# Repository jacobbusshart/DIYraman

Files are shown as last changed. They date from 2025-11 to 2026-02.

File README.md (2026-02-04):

# DIYraman – Open Hardware Raman Spectrometer

  

**Build, understand, and modify your own Raman spectrometer.**
*A modular platform aimed at hobbyists, educators, and low-resource labs.* 

[docs.diyraman.com](https://docs.diyraman.com)
## Introduction

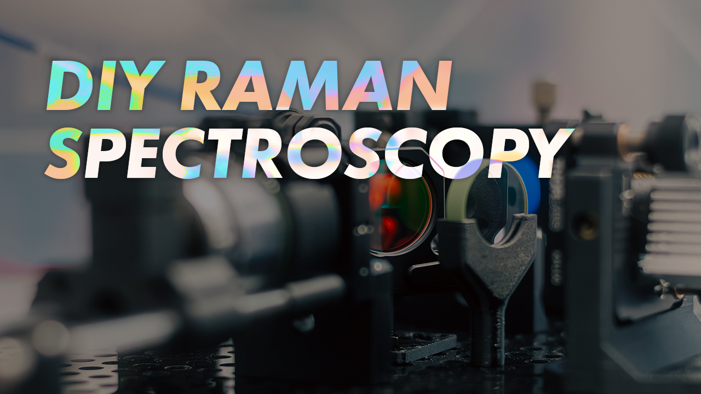
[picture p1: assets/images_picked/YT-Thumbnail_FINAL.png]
https://www.youtube.com/watch?v=EOOmlQH1UKw


[**Click here to watch the Youtube video!**](https://www.youtube.com/watch?v=EOOmlQH1UKw)

Watch the Youtube video to get started and learn about the principles of Raman Spectroscopy, a build overview, along with part considerations, challenges, limitations and practical decisions.  

---

## Project Scope

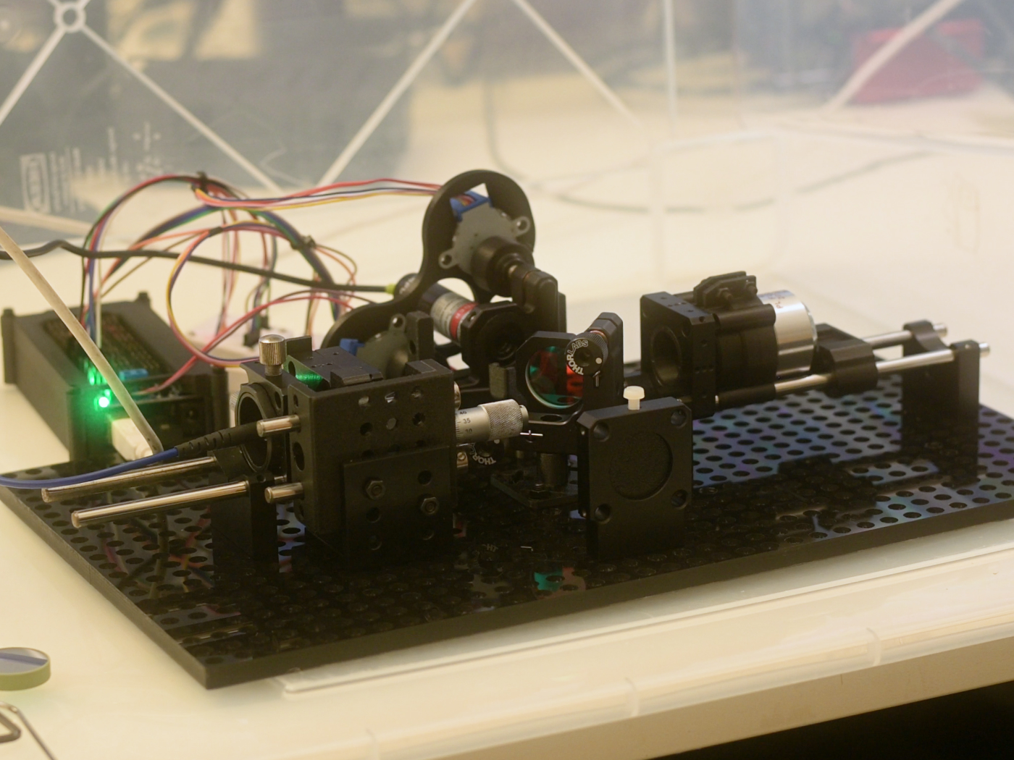
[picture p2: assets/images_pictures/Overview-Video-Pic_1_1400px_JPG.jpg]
Full Assembly in Overpressure Glove Box


**DIYraman** aims to make Raman spectroscopy **replicable, affordable, and fully documented**.

Raman spectroscopy allows for the identification of substances by analyzing how light interacts with molecular vibrations. Historically, this equipment costs tens of thousands of dollars. This project aims to provide instructions for interested tinkerers, who are looking for a documented, applicable build. 

**Key Applications**
* **Identify Substances:** Broad identification of plastics, solvents, and minerals.
* **Qualitative Screening:** Exploratory analysis of pharmaceuticals (e.g., pill composition).
* **Teach Optics:** A hands-on platform for learning spectroscopy and photonics.

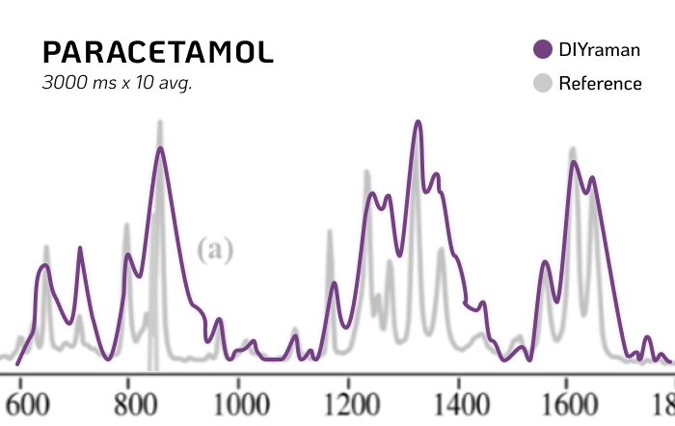
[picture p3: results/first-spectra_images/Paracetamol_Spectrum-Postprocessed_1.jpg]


> 💡 This README is a *project overview*. Detailed build instructions are available on **[docs.diyraman.com](https://docs.diyraman.com)** or can be found in `docs/` on the dedicated pages. An overview of the build instructions can be found further down under [Build Overview](#Build%20Overview).

---

## Component Selection

To balance cost with performance, DIYraman uses a "hybrid" approach: Professional filtering optics combined with repurposed spectroscopy hardware and 3D-printed mechanics.

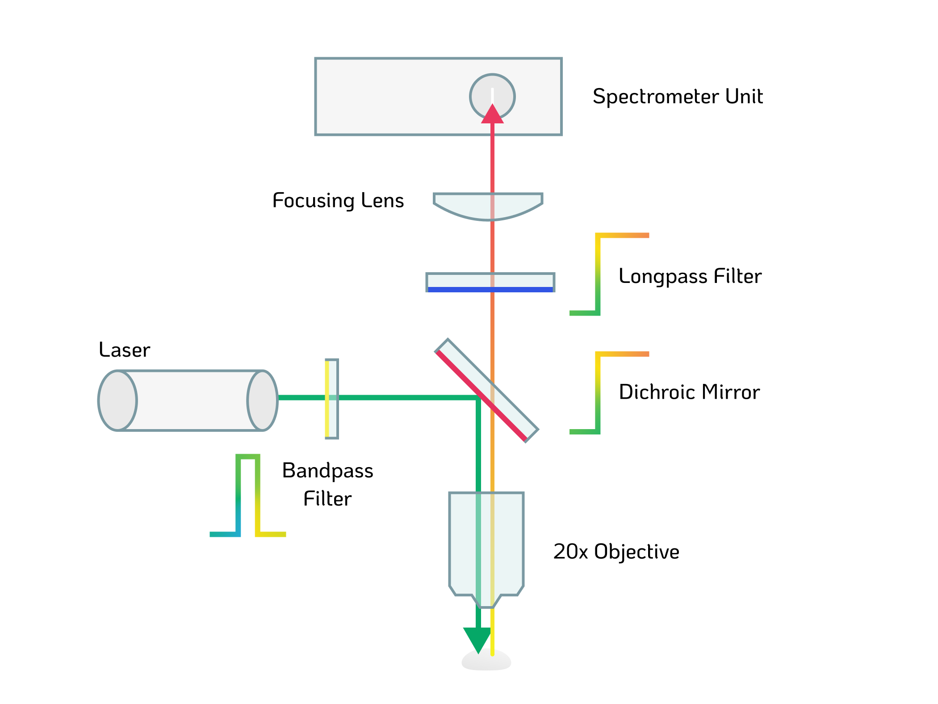
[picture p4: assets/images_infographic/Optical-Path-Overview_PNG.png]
Optical Path Overview


* **Spectrometer:** Surplus BTC100-2S unit (available on [eBay](https://www.ebay.com/itm/143989529085))
* **Excitation:** Cost-effective 532nm DPSS laser pointer
* **Mechanics:** Fully 3D-printable modular stages and enclosures
* **Critical Optics:** High-quality dichroic mirrors and filters (Thorlabs/Edmund Optics) are used to ensure signal integrity.
	* Thorlabs Longpass Dichroic Mirror [DMLP550](https://www.thorlabs.com/item/DMLP550)
	* Thorlabs Longpass Filter [FELH0550](https://www.thorlabs.com/item/FELH0550)

**Bill of Materials**
A detailed cost breakdown and parts list is available in the [BOM (Bill of Materials)](bom/BOM.md) .

---

## Build Overview

The following build path is recommended for a complete and coherent build-experience. The table reflects the current development status of the project's modules. Best viewed and navigated by visiting the [docs.diyraman.com](docs.diyraman.com) page!

*Please note that at this point in time the reproducibility has not been externally validated, as I'm working on the next iteration to optimize and facilitate the entire setup. Until then, view this project as a documentation of my journey into DIY Raman spectroscopy.*

| Step  | Module | Description | Status |
| :---- | :--- | :--- | :--- |
| **0** | **[Introduction](docs/Introduction.md)** | How all the parts work and why they were chosen. | 🟡 Unpolished  |
| **1** | **[Spectrometer-Setup](docs/Spectrometer-Setup.md)** <br>+ [SpectrumStudio-Cheatsheet](docs/SpectrumStudio-Cheatsheet.md)<br>+ [Align-with-Fluorescence](docs/Align-with-Fluorescence.md) | Setup and testing of the B&W Tek spectrometer. | ✅ Ready |
| **2** | **[Dustproof-Workspace](docs/Dustproof-Workspace.md)** | DIY overpressure glovebox construction to keep optics dust-free. | ✅ Ready |
| **3** | **[Core-Assembly](docs/Core-Assembly.md)** | Essential optical assembly to acquire first Raman spectra. | ✅ Ready |
| **4** | **[DIY-Linear-Stage](docs/DIY-Linear-Stage.md)** | DIY build of a low-cost linear translation stage for fine focus adjustments. | 🟡 WiP |
| **5** | Full-Build | Motorization and integration of Linear Stage. | 🔴 Unpublished |
| **6** | Software / GUI | Custom acquisition and visualization software. | 🔴 Unpublished |

> **Status Key:** ✅ = Verified & Documented | 🟡 = Usable, Docs in Progress | 🟠 = Draft / Unstable | 🔴 = Planned / Unpublished

---

## Capabilities

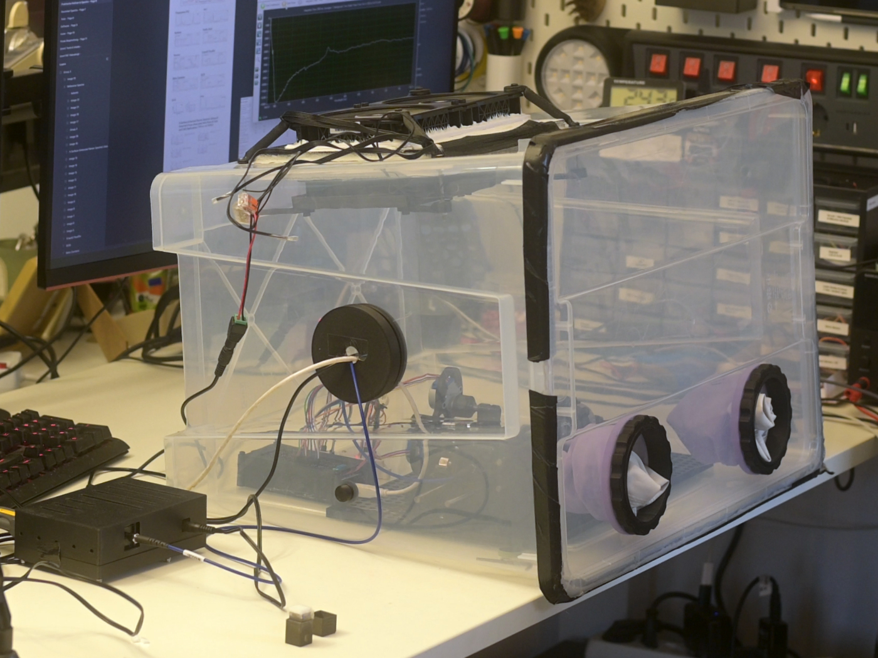
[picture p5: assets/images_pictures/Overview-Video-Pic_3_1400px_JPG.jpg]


| Feature | Specification |
| :--- | :--- |
| **Spectral Range** | Stokes region > ~600 cm⁻¹ |
| **Sample Type** | Solids & Liquids (Cuvette holder) |
| **Resolution** | estimated 35 cm⁻¹ (dependent on spectrometer input slit / sensor & laser beam quality) |
| **Safety** | Wear laser safety protection during alignment or until the optical path is entirely enclosed! |

> 🧪 **Drug / counterfeit screening**  
> The system can be used for *exploratory, educational* screening of unknowns (e.g. counterfeit pills) but **must not** be treated as a validated forensic tool. **Always cross-check with certified methods!**

---

## Repository Structure

- `docs/` — the build instructions hosted on [docs.diyraman.com](docs.diyraman.com)
- `bom/` — BOM tables and sourcing notes  
- `parts/` — files for printing / 3d-models (.stl)  */feel free to contact me for the full Fusion (.F3D) project file*
- `assets/` — all images, diagrams, misc. media  
- `results/` — example spectra / early outputs  
- `software/` — acquisition and post-processing software (unreleased, planned)

---

## Contributing

Contributions are welcome from makers, scientists, and coders. Areas for contribution include:

1. **Testing:** Reporting unclear steps or missing files in the documentation.
2. **Design:** Proposing improved mechanical mounts or variants.
3. **Coding:** Assisting with the upcoming GUI/Firmware.
4. **Sharing:** Submitting example spectra.

**Citation:** If utilizing DIYRaman for research or teaching, please cite the project:

> **DIYRaman - Open Hardware Raman Spectrometer (GitHub)** 
> _Jacob Busshart, DIYraman.com_

---

## Licenses

A modular licensing structure is used to ensure maximum freedom for hardware and software usage.

- **Hardware (CAD, Schematics):** [CERN-OHL-S v2](LICENSES/CERN_OHL_S_V2.txt)
- **Documentation (Guides, Images):** [CC BY-SA 4.0](LICENSES/CC-BY-SA-4.0.txt)
- **Software (Firmware, GUI):** [MIT License](LICENSES/MIT.txt)

---

### Acknowledgements

_Built on the shoulders of the open science community._

- [OpenRaman.org](https://www.open-raman.org/) & [ThePulsar.be](https://www.thepulsar.be/article/diy-raman-spectroscopy/)
- [PhysicsOpenLab.org](https://physicsopenlab.org/2022/04/22/backscattering-raman-system/)
- [LaserPointerForums Community](https://laserpointerforums.com/threads/b-w-tech-spectrometer-473-module-setup-mods-info.101467/)

---

*NOTE: Some parts of the written documentation have been formatted or translated using AI.*

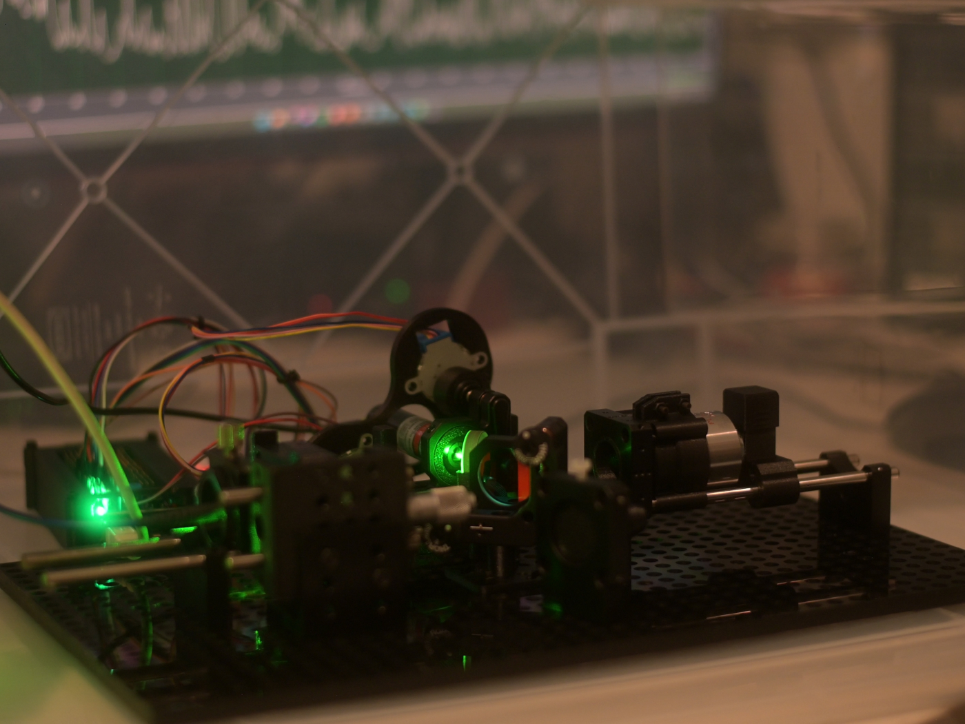
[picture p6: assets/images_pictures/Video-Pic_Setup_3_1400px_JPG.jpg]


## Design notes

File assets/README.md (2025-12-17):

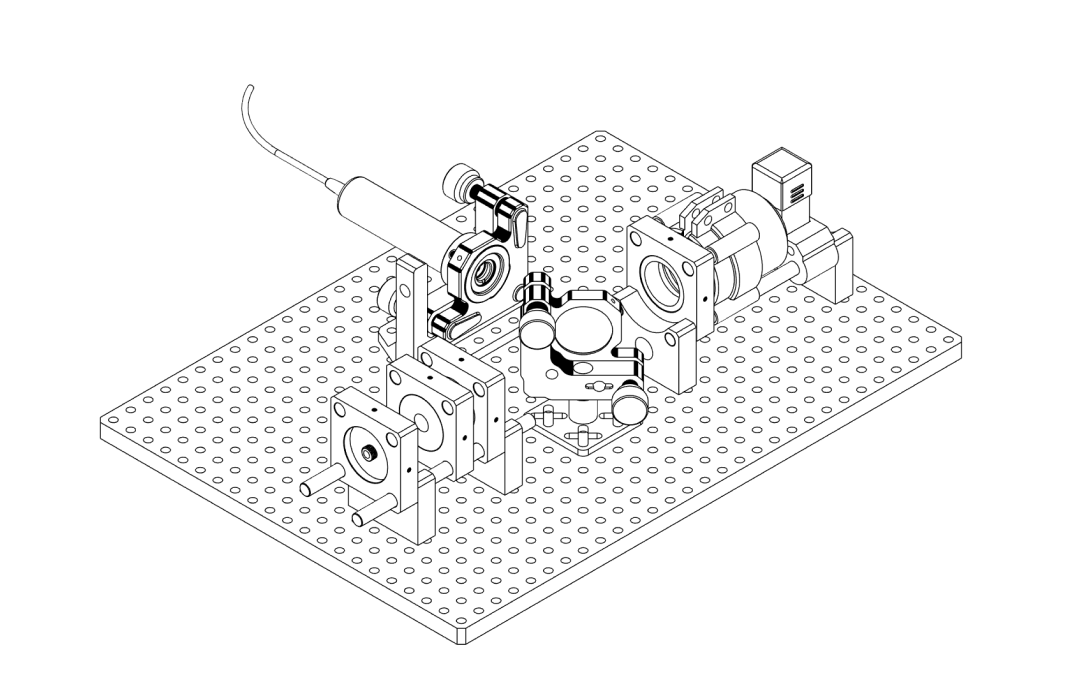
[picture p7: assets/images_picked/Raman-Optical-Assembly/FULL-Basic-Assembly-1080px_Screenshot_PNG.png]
| ***[Core-Assembly](../docs/Core-Assembly.md)*** | <br><center>*abridged version*</center><br> |
| --- | --- |
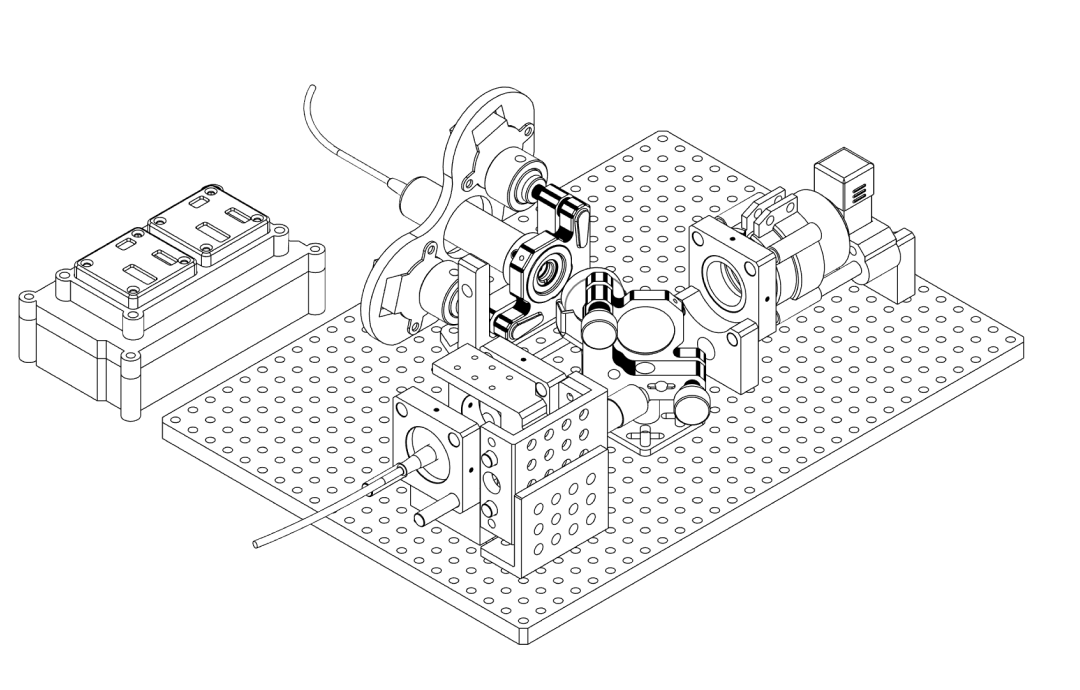
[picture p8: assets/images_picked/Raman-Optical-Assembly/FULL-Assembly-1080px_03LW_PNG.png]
| ***[Full-Build](../docs/Full-Build.md)*** | <br>**<center>*current version*</center>**<br> |

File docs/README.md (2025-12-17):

[Overview - README](../README.md)
[Spectrometer-Setup](Spectrometer-Setup.md)
[Dustproof-Workspace](Dustproof-Workspace.md)
[Core-Assembly](Core-Assembly.md)
[Align-with-Fluorescence](Align-with-Fluorescence.md)
[SpectrumStudio-Cheatsheet](SpectrumStudio-Cheatsheet.md)
[DIY-Linear-Stage](DIY-Linear-Stage.md)
[Full-Build](Full-Build.md)

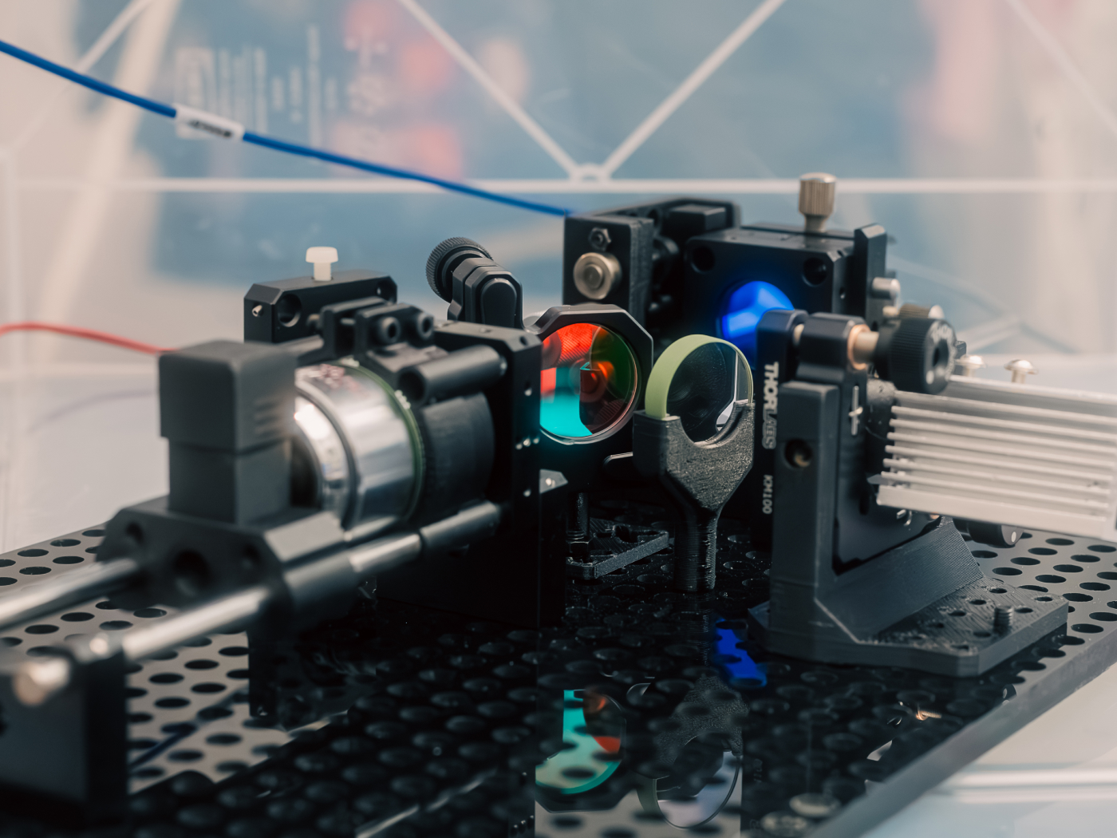
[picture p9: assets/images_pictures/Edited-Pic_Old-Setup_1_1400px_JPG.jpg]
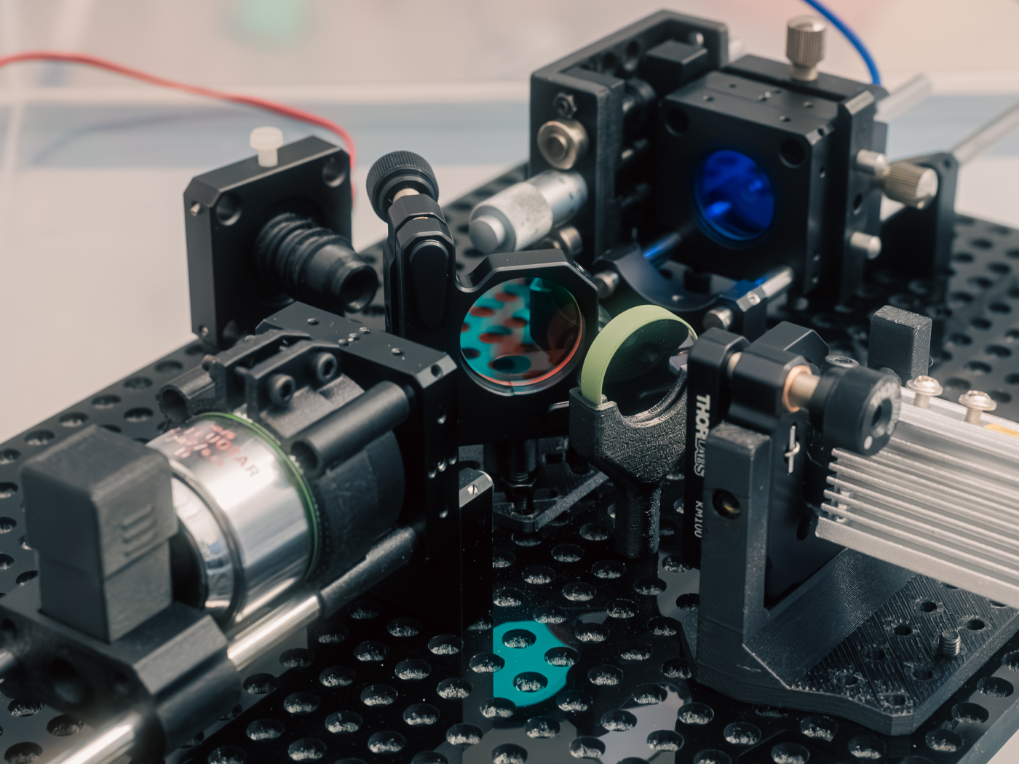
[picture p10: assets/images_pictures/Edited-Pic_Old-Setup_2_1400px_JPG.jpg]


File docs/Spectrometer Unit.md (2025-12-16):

# Measuring light - Spectrometer Unit

Spectrometer unit with printed case

Prepare, house and use the surplus **B&W Tek BTC100-2S** spectrometer module as the detector for the DIYraman system. 

This page focuses on the practical steps you need to:

- **Inspect and clean** the used unit  
- **Mount it** in a simple printed housing  
- **Power it up** and talk to it over RS-232  
- **Acquire a first spectrum** and apply a basic wavelength calibration

| Specs | |
| --- | --- |
| Range | ~400nm - 650nm |
| Grating | 1800l/mm, blaze at 500nm |
| Input slit | 100µm (wide) |
| Coupling | SMA905 fiber |
| Detector | Sony ILX511 linear CCD |
| Resolution | 2048 pixel spectrum |
| Power | 5V barrel jack |
| Connection | RS-232 serial |

View inside the optical assembly of the Spectrometer Unit BTC100-2S

> [!ABSTRACT] Learn more about the BTC100-2S
> For an in-depth look into the capabilities and internal design of this model, visit this blog post: **[“Home Optical Spectrometry: The B&W Tek BTC100-2S”](https://www.sevarg.net/2023/01/28/bw-tek-btc100-spectrometer/)**

---

## Parts and Materials

> [!EXAMPLE] Visit the complete Bill of Materials
> Everything you will need, both printed parts and sourced parts, along with their cost and supplier, can be viewed in the dedicated [BOM](../bom/BOM.md)!

### Sourced parts

| Qty | Name | Model / Spec | Notes |
| --- | --- | --- | --- |
| 1x  | Spectrometer unit | [B&W Tek BTC100-2S](https://www.ebay.com/itm/143989529085) | Or any other spectrometer - ideally with SMA905 input, if you use fiber. |
| 1x  | Fiber optic cable, 200 μm | Any, SMA905-SMA905 1m VIS-IR 200um | - |
| 1x  | Data cable | RS-232 to USB | Choose a chipset compatible with your OS (many FTDI / Prolific chips work reliably). |
| 1x  | Power supply | 5V, ~3A, DC barrel jack | |
| 1x  | Calibration lamp | Dedicated calibration / CFL / mercury-vapor lamp | Needs several sharp lines near ~550 nm for wavelength calibration. |

> [!TIP] Spectrometer cost consideration  
> The used BTC100-2S board - although quite old - will still be significantly cheaper than  buying parts for a DIY spectrometer. If you are lucky (or persistent enough) to spot a great deal of a more modern unit, that's even better.

### Printed parts

| Qty | Part name (.stl) | Print preview |
| --- | --- | --- |
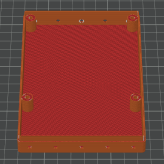
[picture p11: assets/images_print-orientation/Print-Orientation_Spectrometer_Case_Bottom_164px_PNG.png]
| 1x  | `Spectrometer-Case_Bottom` |  |
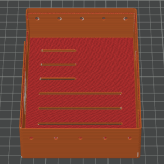
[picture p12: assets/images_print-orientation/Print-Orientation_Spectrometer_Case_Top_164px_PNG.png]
| 1x  | `Spectrometer-Case_Top` |  |
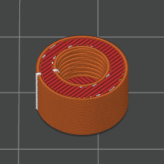
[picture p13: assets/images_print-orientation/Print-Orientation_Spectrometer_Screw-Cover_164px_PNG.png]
| 1x  | `Spectrometer_Screw-Cover` |  |

> [!WARNING] Health & safety – sanding fibre-filled plastics  
> When sanding or trimming 3D-printed parts made from PETG-CF or other fibre-filled filaments, wear at least a surgical mask. Fine carbon or glass fibres can accumulate in your lungs with repeated exposure.

---

## Inspect and Clean the Spectrometer

Before printing parts or powering anything, make sure your spectrometer arrived intact and is free of loose contamination.

### Visual inspection

Spectrometer unit out of the box  
Spectrometer top-rear view with SMA905 input  
Underside of the PCB

Check:

- The **PCB** is not bent, cracked or visibly repaired.  
- The **SMA905 input stud** is straight and firmly attached.  
- The **50 µm slit window** in front of the spectrometer optics is intact (no cracks or chips).  
- The **heatsink, fan and connectors** are firmly attached and not visibly corroded.  

If you spot severe mechanical damage (cracked PCB, broken slit, missing components), contact the seller before investing further time.

### Cleaning

Close-up of the input with 50 µm slit

1. Use a blower or compressed gas to gently **dust off the PCB and the fan**.  
2. Lightly dampen a lint-free cloth with **99% IPA**.  
3. Wipe non-optical surfaces: metal case, heatsink, fan frame, backside of the PCB.  
4. Use cotton swabs with a small amount of IPA to clean tight areas around connectors and edges.  
5. **Do not touch** the slit glass, sensor or any exposed optical surfaces directly.  

> [!WARNING] Avoid optical surfaces
> Don't disassemble the spectrometer's optical assembly or try to adjust any of its components, unless you know what you're doing. Avoid getting any liquid into the input or onto any optical surface. 

---

## Housing and Mounting

The BTC100-2S is an exposed PCB assembly. A simple printed case protects it from dust, stray light and mechanical damage, and makes overall handling easier.

Spectrometer with printed case, standoffs and screws

> [!TIP] Print seams for precise holes  
> Avoid seam placement directly inside precise holes. Random seam positioning often yields better clearance for functional features like standoffs and connector cut-outs.

### Install PCB standoffs

1. Place the `Spectrometer-Case_Bottom` on your work surface.  
2. Identify the four mounting bosses that match the BTC100-2S PCB hole pattern.  
3. Screw the included standoffs into these bosses.
4. Confirm that the height of the standoffs provide enough clearance.

### Mount the spectrometer in the case

1. Carefully lower the BTC100-2S onto the standoffs so that:  
   - All four mounting holes align with the standoffs.  
   - The SMA905 input lines up with the circular opening in the case front.  
2. Fasten the PCB using four M3 screws, tightening them evenly.  
3. Place the `Spectrometer-Case_Top` on the bottom part and close the housing.  

---

## Powering On and Connecting

This section gets the spectrometer powered and talking to your computer.

### Warm-up behaviour

1. Connect the 5V / ≥3A power supply to the barrel jack.  
2. Plug it in – there is no power switch, so you immediately hear the small fan spin up.  
3. Leave the unit on for **≈ 10 minutes** before serious measurements.

> [!INFO] Warm-up time? Cool-down time!  
> The BTC100-2S uses a thermoelectric cooler (TEC) plus heatsink and fan to cool and stabilise the sensor temperature. Starting measurements immediately after power-on leads to higher background noise and random spikes until the temperature settles!

### RS-232 to USB adapter

- Connect the RS-232 adapter between the DB-9 port and your PC.
	- Windows is assumed as the operating system, although it is possible - and tested -to run the original software inside of a virtual machine on an M1 Mac.

> [!NOTE] USB–RS-232 compatibility  
> Some USB-RS-232 chipsets behave poorly on non-Windows systems or inside virtual machines. A mid-range cable from a known brand (e.g. FTDI-based) tends to work more reliably than ultra-cheap clones, according to a forum post.

---

## Acquiring your First Spectrum

For initial testing, use the original B&W Tek software (“Spectrum Studio”) to confirm that communication and data acquisition work as expected.

> [!TIP] Quick UI reference - Cheatsheet 
> See the dedicated page [**Spectrum Studio Cheatsheet**](Spectrum%20Studio%20Cheatsheet.md) for screenshots and an overview of the most relevant controls.

### Software setup

1. Start Spectrum Studio with the spectrometer powered and connected.  
   - In case the program isn't working or executing correctly, run it in **compatibility mode**.
	   - Right-Click > "*Properties*" > "*Compatibility*" > "*Run in comp...*" > Check Box and Select "*Windows 7*" > Press "*OK*".
2. If it does not auto-detect the device:  

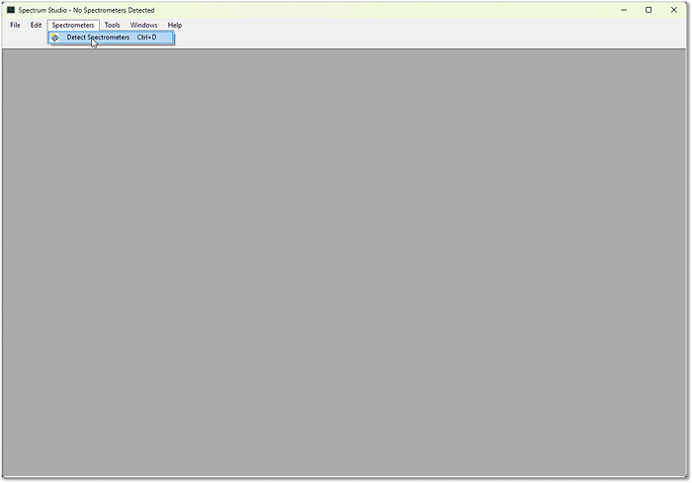
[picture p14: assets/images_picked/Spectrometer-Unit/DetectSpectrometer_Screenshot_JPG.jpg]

   - Click **“Detect Spectrometer”** in the toolbar.  
   
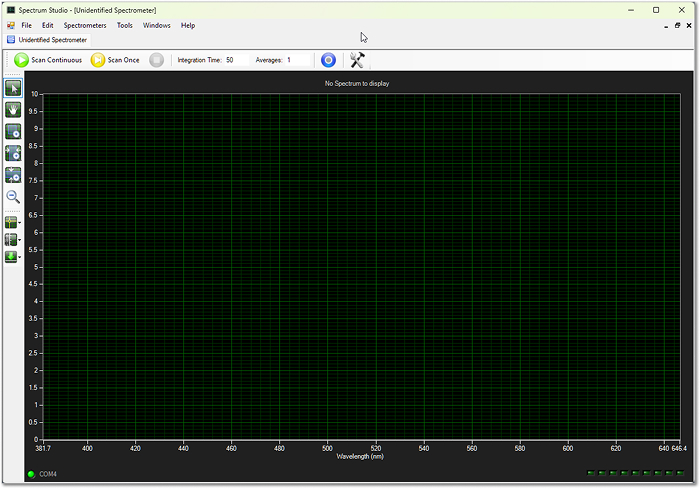
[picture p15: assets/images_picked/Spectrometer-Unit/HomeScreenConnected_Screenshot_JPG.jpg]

   - Wait for the blank graph to appear.  
3. Open the **“Calibrate”** window ( - settings icon at the right of the toolbar).  
4. Set parameter **C1 = 1** at the bottom and confirm with **OK** – this enables the wavelength calibration features you will need later.

### Integration time and averaging

The spectrometer behaves much like a camera sensor:

- **Integration time** ≈ camera shutter speed.  
  - ~50 ms: quick checks and rough alignment.  
  - 1500–20000 ms: typical range for final Raman measurements.  
- **Averages**: number of individual spectra that will be acquired and averaged, even when you press **“Scan Once”**.  
  - During acquisition, the software shows the most recent scan.  
  - At the end of the series, it updates the display with the averaged (and optionally background-subtracted) spectrum.

> [!TIP] Avoid saturation  
> Aim for a maximum signal well below the top of the y-axis. Saturated pixels distort line shapes and make later processing more difficult.

### Capturing and subtracting background

1. Block the input slit (e.g. with your finger, a printed cap or tape).  

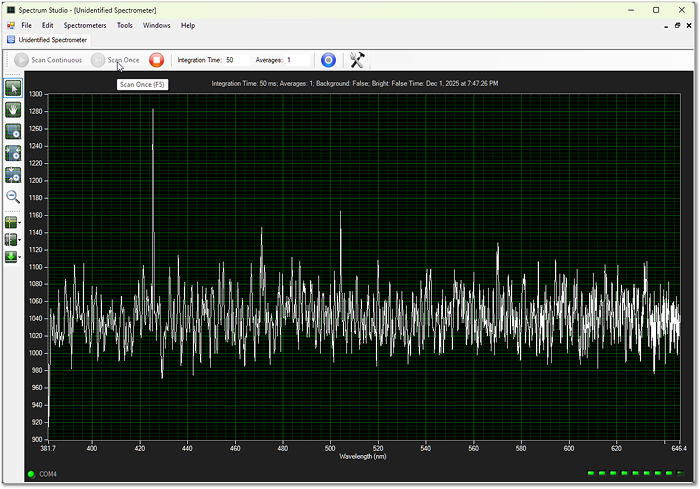
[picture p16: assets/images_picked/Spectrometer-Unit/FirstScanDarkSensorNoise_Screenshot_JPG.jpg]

2. Start an acquisition  with typical settings (e.g. 250–2000 ms, a few averages).  
3. Use the **green arrow icon** in the left toolbar ( - background submenu) to:
   - Capture the current spectrum - the noise print of the dark sensor - as background.

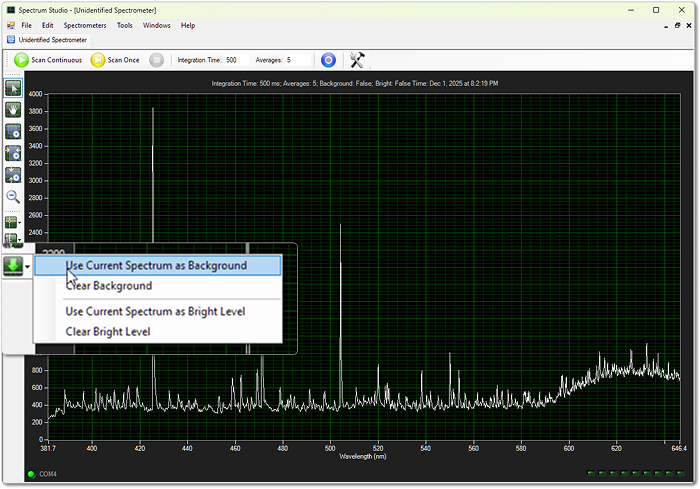
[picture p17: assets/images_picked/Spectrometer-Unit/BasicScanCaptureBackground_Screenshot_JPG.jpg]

4. Scan again to capture a test - using a dedicated light source or just your room

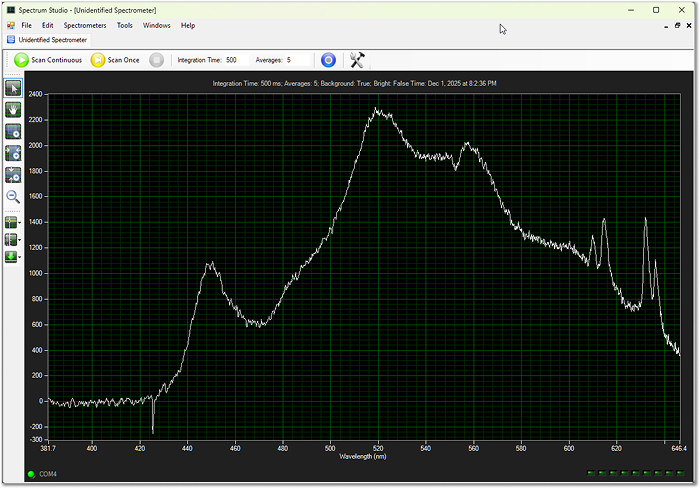
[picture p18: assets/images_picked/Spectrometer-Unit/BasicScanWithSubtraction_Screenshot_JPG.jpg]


This background remains active and will be applied on all subsequent spectra until you clear or update it. The table below highlights the difference in quality of the final spectrum - with and without the subtracted sensor noise.

| With background subtraction (clean) | Without background subtraction (raw) |
| --- | --- |
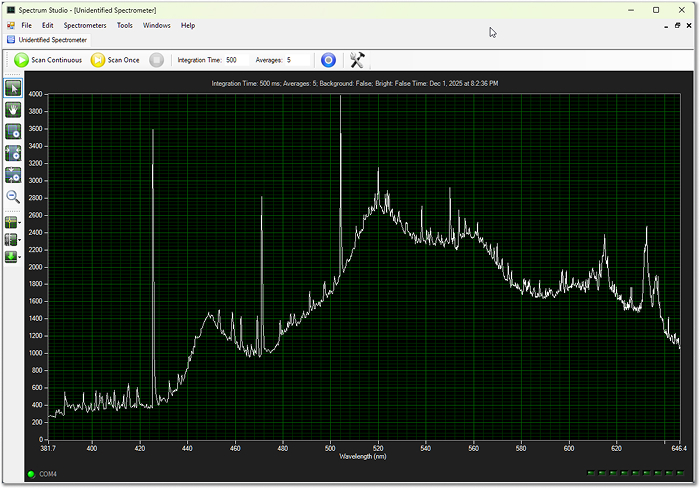
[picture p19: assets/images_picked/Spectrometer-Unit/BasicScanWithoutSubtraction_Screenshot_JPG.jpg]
|  |  |

> [!WARNING] Re-acquire background after changing integration time  
> Whenever you change the **integration time**, capture a **new background**. Spectrum Studio does not automatically warn you or clear the old background – it will otherwise subtract an incorrect background.

---

## Wavelength Calibration

Proper wavelength calibration maps each CCD pixel index to a physical wavelength in nanometres. This step is essential for correctly scaled Raman shifts later on.

### Choose a calibration source

A good calibration source has:

- Several sharp, well-documented emission lines  
- Lines close to the region of interest (around 550 nm for a 532 nm Raman system)

Suitable options:

- Mercury-vapour lamp (ideal, easiest)  
- CFLs with visible mercury lines (abundant, low-cost)  
- Dedicated calibration lamps from astronomy suppliers (more expensive)

You can find reference spectra and line lists for mercury-vapour lamps in many spectroscopy references and online databases.

### Record calibration data

1. Acquire and apply a background of the sensor noise.  
   - If the spectrometer was just powered on, leave it running for roughly 10 minutes until the measured noise stabilizes.  
2. Turn off or dim ambient lights in the room to avoid stray lines.  
3. Place the calibration lamp so light enters the slit (directly or via SMA fibre, if used).  

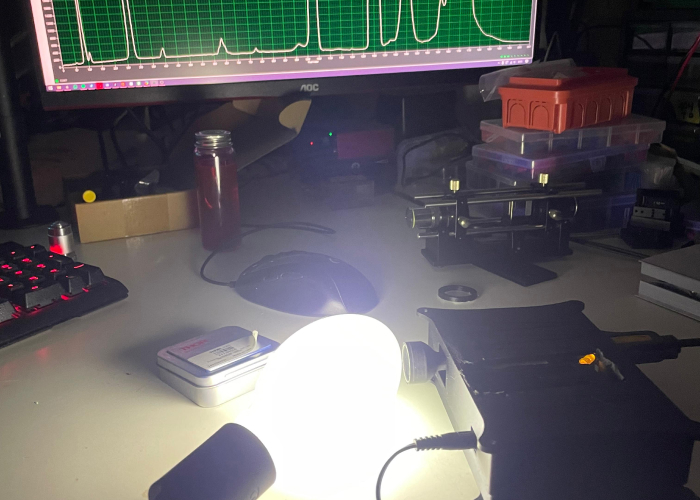
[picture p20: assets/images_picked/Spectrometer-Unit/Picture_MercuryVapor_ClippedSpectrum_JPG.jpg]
Mercury-vapour lamp very close to the input slit

*A mercury-vapour lamp was bought cheaply on eBay, along with its required ballast. This is an old picture with the lamp placed too close to the input slit.* 

4. Adjust integration time until you get:  
   - Clearly visible peaks  
   - No saturated pixels  

Now use the software’s **cursor tool** (two icons above background subtraction in the left toolbar):

5. Drag the vertical line to each prominent spectral peak.  
6. For each peak, write down:
   - The **pixel index** (x-axis value before calibration)  
   - The **known wavelength** (from your reference data)

Collect at least **4 calibration points** across the usable range – air for more points to give a better fit.

### Least-squares fitting in Spectrum Studio

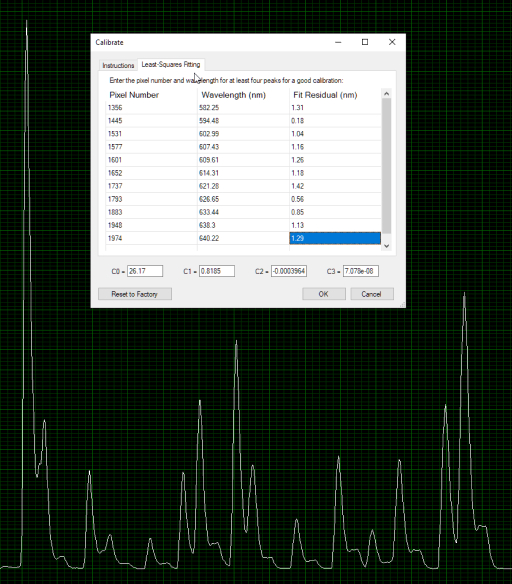
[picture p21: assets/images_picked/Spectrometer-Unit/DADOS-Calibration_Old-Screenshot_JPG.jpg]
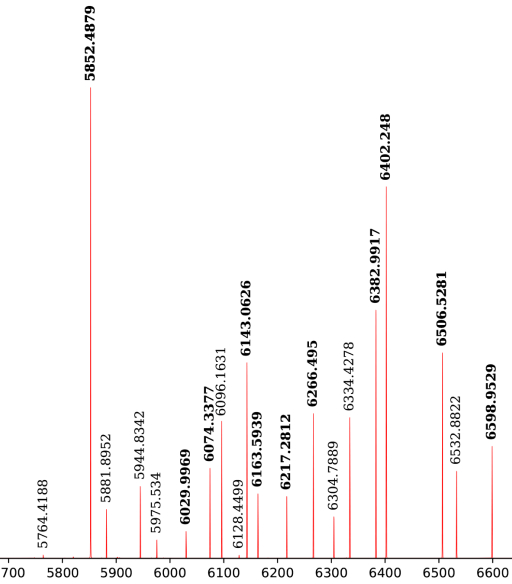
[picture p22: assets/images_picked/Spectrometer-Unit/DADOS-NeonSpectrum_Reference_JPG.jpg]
| <br> | <br> |
| --- | --- |
| *Old image of the first ever calibration done using a dedicated calibration lamp. Least-squares fitting with all pixel numbers and respective wavelengths added - fit residual is calculated automatically.* | *This was the reference spectrum provided with the cheap calibration lamp, whose wavelengths lie mostly in the upper range of the Raman's design.* |

1. Open the **Calibrate** window again.  
2. Switch to the **“Least-Squares Fitting”** tab.  
3. Enter all recorded **pixel indices** and their respective **wavelengths** into the table.  
4. Let the software compute the calibration coefficients.  
5. Write the 4 calibrated coefficients down or take a screenshot for future reference.
6. Confirm with **OK**, then take another scan.
   - The coefficients are written and **saved to the spectrometer's internal memory**.
   - The calibration only gets overwritten, if the coefficients are changed (or automatically calculated).

The x-axis should now be displayed directly in **nanometers (nm)** instead of raw pixel numbers.

---
## Final check

> [!DANGER] Laser safety  
> Never look directly into the beam or reflections, and be especially careful with cheap DPSS lasers that may leak significant invisible infrared.

1. Gently shine a green 532 nm laser at the entrance slit.  
   - Avoid over-exposing the sensor; use reflections or a diffuser if needed.  
2. Acquire a spectrum and check the main laser line:  
   - Expect a peak somewhere around **528–536 nm**, depending on laser quality and calibration accuracy.  
3. If the peak is significantly off, re-check your calibration points and repeat the least-squares fitting.

---

## Continue reading

- [Overpressure Glove Box](Overpressure%20Glove%20Box.md)
- [Basic Raman Optical Assembly](Basic%20Raman%20Optical%20Assembly.md)
- [Linear Translation Stage](Linear%20Translation%20Stage.md)
- [Spectrum Studio Cheatsheet](Spectrum%20Studio%20Cheatsheet.md)

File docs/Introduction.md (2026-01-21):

# Introduction

## Background 

I have been fascinated with Raman spectroscopy for a while now, after looking into substance identification techniques. Late last year I decided on starting to build and document a DIY Raman spectrometer system from cheap, reused components. The primary end-goal was to provide an affordable platform to (qualitatively) identify counterfeit pills and characterize the chemical structure of unknown compounds. Fortunately I was able to work on this as a semester project. Note that I study Product Design - not (optical) engineering - and this is more of a passion project published in good faith to contribute to the open-hardware community . I would like to additionally note that, while the finished build works as a Raman spectrometer, expect there to be sub-optimal implementations or bad practices incorporated throughout. Feel free to reach out, if you have any suggestions, corrections or criticism.  
After reading and researching different publications and sources I came to be disappointed by the conclusion that there weren't any accessible step-by-step instructions that would facilitate the actual build. This encouraged me further to properly document design considerations, practical implementations and challenges along the way.

## How it Works

### Spectrometer
After reading a bunch of sources, I realized that building the spectrometer itself was not very cost efficient. I decided on getting it on eBay, which also avoids the hassle - especially for the unexperienced user - of having to align a guide mirror, diffraction grating and assembling the electronics or PCB of the detector. The B&W Tek unit offered a great compromise in cost and performance, despite its decade old age and a relatively bad resolution by today's standards. As these specs can be upgraded, for example, by replacing the diffraction grating, upgrading the CCD, using a smaller input slit or just optimized by rotating the internal optics as to increase resolution in the wavelength range of interest. 
### Sample
For the sample assembly, there are various options, which also depend on which type of Raman configuration is chosen. There are mainly three possible configurations: backscattering, which means the collection of the Raman signal emitted from the sample is collected by the same optic (microscope objective in this case) through which the laser / excitation beam is focused. Then there is a 90° configuration, which is especially interesting for liquids. Here the laser beam and the collected Raman signal are offset by 90° - so when illuminating the sample from the front, the scattered Raman is collected to its left or right. Lastly, there is transmission Raman, which works similarly by shining the excitation beam 'through' the sample - beam coming in from the front and leaving out the back, where the laser line is filtered and the Raman signal collected. The different configurations come with unique compromises in terms of general capabilities, reliance on tolerance or alignment difficulty.
As backscattering allows for a strong Raman signal to be collected, once it's aligned properly - and I already bought the cuvettes, which are frosted on the sides, I decided on this. This can allow for a relatively compact build, if desired or hard-mounted (in final assembly).

For the sample holder there are mainly three options: leave out holder entirely, use a single-use (plastic) cuvette / tube or use a reusable quartz glass cuvette for optical applications. Quartz glass is desired because silica is quite inert and can be polished to an excellent surface finish, while also being resistant against most corrosive chemicals. 
### Laser 
The ideal excitation source would be an entirely monochromatic (single wavelength) light source, with a minimal focus spot size. A green laser at 532 nm was chosen, as optical components in this range are cheap, laser pointers widely available and the performance sufficient. Note that generally, lower wavelengths will excite fluorescence in many molecules. This will make Raman measurements mostly impossible on these compounds, unless it occurs very faintly. Most systems meant for quick identification of unknown powders in the field feature a dual-wavelength system, i.e. 532 nm and 785 nm or a single (near) IR excitation source - mostly 785 nm or 1064 nm. For general usage, an IR excitation laser is desired but comes with significant challenges. When compared to a 532 nm system, a 785 nm laser - at same output power - provides almost 16x less Raman signal. On the other hand, since fluorescence always occurs stokes-shifted (upwards), at higher wavelengths, most fluorescence is mitigated and can be avoided, allowing for a broader substance range to be identified. Unfortunately, especially for a beginner, I decided against the use of an infrared laser, as it is also mostly invisible to the human eye and thus incredibly dangerous at higher powers. The filtering optics and spectrometer architecture also differ by a lot and are generally only available at much higher cost. As 532 nm offers strong signal intensity, abundant detector technology, low risk of sample damage, while being highly affordable - at the cost of some fluorescence.
The selected laser power is also an important consideration. Broadly speaking, most 532 nm systems use a laser between 30mW - 100mW, though some can also get away with even lower power like 10mW. To offset relatively poor beam performance, a higher power output can be chosen for cheaper models. Be careful though, cheap 532 nm DPSS lasers often leak dangerous amounts of infrared, which is invisible and destructive to your eye and will also completely swamp the spectrometer's detector. To counter that, a bandpass filter or also a IR blocking filter can be implemented immediately after the laser.
The laser is focused onto the sample by using an objective, and since in a backscattering configuration the sample focusing lens also serves as the collection optic for the Raman scattering, the cheapest option is a used infinity-corrected microscope objective. Infinity-corrected is essential here, since in a cheaper microscope lens with fixed distance, the Raman signal exiting out of the back would not be collimated (parallel rays) and generally sub-optimal for the final filter and focusing assembly that guides the signal through the spectrometer's input slit. The working distance of the 20x / 40x objective is a critical attribute and directly correlated with the width of the cuvette. If the WD is shorter than the cuvette's material is thick, you will be unable to focus the material inside and end up with no usable signal or detect the Raman signal of just the cuvette. 
### Filtering
To filter out the incredibly weak Raman signal from the excitation wavelength - the visible Rayleigh scattering - two filters are employed in total. The first being a dichroic longpass mirror, which works as a selective mirror: reflecting all wavelengths below the cut-on, while letting everything above pass through. This is convenient as it allows the laser to be set-up perpendicular to the sample focusing and collection axis while also serving as the first filtering stage for the collected signal. 
The cheapest high-quality option here was the Thorlabs DMLP550, which has a cut-on at 550 nm. If we assume the laser performs exactly as intended, all of its emitted light would be at exactly 532 nm - below the filter's cut-on wavelength - and will thus be reflected at a 45° angle of incidence. 
Raman scattering is unique in that it is shifted in wavelength, more strongly in the *Stokes* region, which lies above the excitation wavelength (here at > 532 nm +), but also in the *Anti-Stokes* region, which occurs as a shift below the laser's wavelength (here at < 532 nm). Since we don't use a more expensive notch filter that selectively blocks out exclusively 532 nm, the final Raman spectrum will only feature parts of the Stokes shifted spectrum and no Anti-Stokes region at all. Out of cost and availability constraints, the chosen cut-on wavelength is quite a bit higher than the excitation. In practice this means that the Stokes region will be clipped up until 550 nm - so the difference of the filter's cut-on and the excitation source's wavelength, which comes out at roughly 18 nm and translates to broadly 500cm^-1 in the final Raman spectrum. This is a compromise but also not detrimental, because many molecules display most of their characteristic Raman activity in the *fingerprint region* between 400cm^-1 and 1650cm^-1. Keep this in mind as a key limitation though. 

After passing straight through the dichroic longpass mirror, the signal is filtered a second time by a longpass filter. Since Raman scattering is up to 10.000.000x weaker than the Rayleigh scattering, a second filter is recommended to clean up any remaining laser light that would otherwise saturate or impact the detector.
Optical density is a critical specification here, as anything below OD5 (higher is better; more filter performance), is unsuitable due to the substantial amount of light still leaking and passing through. The model used is a Thorlabs FELH0550, which is a simple filter that - unlike the dichroic mirror - is not mounted at 45° incidence angle. In fact it has to sit as flat or with as little of an angle as possible, perpendicular to the incoming pre-filtered signal. Even 1° of tip or tilt in any direction will shift the filter's cut-on wavelength noticeably and will significantly harm its OD performance.
### Focusing
In the final stage the collimated filtered signal - that should now exclusively consist of Raman wavelengths >550nm - has to be focused onto a tiny spot. This is done using a focusing lens or by using another microscope objective to allow it to pass into the 200um optical fibre (or the spectrometer's 50/100um input slit directly). In addition, a simple linear translation stage was built, so the focusing lens could be precisely moved along the axis to achieve optimal focus.  
### Acquisition
With the spectrometer wavelength calibrated and set-up properly, the raw Raman signals can then be captured. To achieve a good signal-to-noise ratio (SNR), it is often best to experiment with different exposure times. For most samples, I found 1500 - 3000ms to yield the cleanest results overall. The occasionally used upper range lies between 5000 - 7000ms but isn't necessary for most acquisitions. Note that during initial testing of different configurations and figuring out what tolerances and precision would be needed, I cranked exposures up to 20 - 25s (25000ms), as the whole system and beam path wasn't sufficiently aligned.
### Post-Processing
After acquisition, the raw spectrum is exported as a CSV to be post-processed. The goal here is to make the spectrum more legibile, reproducible and expressive. There is a wide variety of proven (and novel) algorithms and techniques to process the spectrum. At first, the baseline is subtracted to flatten the spectrum and peak / band intensities are proportionally adjusted. A process known as de-spiking is applied, to remove random spikes caused by cosmic rays striking the sensitive CCD sensor, especially during long exposure acquisitions, manifesting as intense narrow bands scattered throughout. Afterwards, a denoising process averages and smooths the data to clean it up visually. Of course, the respective Raman shift will have to be applied and peaks fitted, the spectrum cropped and then exported or used with a database to automate substance identification by comparing against a dataset of verified peak locations, widths and intensities. More detailed information will be available on the software page, as the post-processing pipeline can be a highly intricate process of which I can only lightly scratch the surface. 

## Get Started

0. [BOM](../bom/BOM.md) - Visit the bill of materials to gain a better understanding of the essential parts
1. [Spectrometer-Setup](Spectrometer-Setup.md) - Familiarize yourself with the B&W Tek spectrometer unit
2. [Dustproof-Workspace](Dustproof-Workspace.md) - Build a dustproof box to protect the expensive optical components
3. [Core-Assembly](Core-Assembly.md) - Print and build the core assembly of the system
4. Additional documents:
	1. [DIY-Linear-Stage](DIY-Linear-Stage.md) - Recommended for the final assembly
	2. [Align-with-Fluorescence](Align-with-Fluorescence.md) - Handling and preparing the fluorescent dye solution for alignment
	3. [SpectrumStudio-Cheatsheet](SpectrumStudio-Cheatsheet.md) - Quick overview of the original 'Spectrum Studio' software 
	4. [Full-Build](Full-Build.md) - Final integration of all components and partly motorizing adjustment

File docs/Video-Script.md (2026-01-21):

# Youtube Video Script

> [!NOTE] This is the **raw** version of the video script
>  Note that some parts didn't make it into the final cut and might not have been recorded verbatim.

## Intro 

In this video, I’ll show you how this little box can identify unknown materials using a laser, why Raman spectroscopy is such a fascinating technique, and how I built a working system at a budget below a thousand euros.

Hi, I’m Jacob - and this is my DIY Raman spectrometer.

Here’s a real measurement taken with this exact build: a common paracetamol tablet. I crush it into a homogeneous powder, load it into a quartz cuvette, give the spectrometer a bit of warm-up time so the detector stabilizes. Then I turn on the laser and take an “exposure” - similar to the shutter in a digital camera.

For this setup, I usually land somewhere between one to ten seconds per acquisition, and I’ll average multiple exposures to improve the signal-to-noise ratio or legibility.

And this is the result: a spectrum - basically a fingerprint made of peaks.

By itself, that plot is just a jagged line. The magic happens when you compare it against a reference spectrum from literature or a reference database. Even without post-processing, you can already see many of the same peak positions lining up. That’s the moment where Raman becomes rewarding and the struggles of the build finally pay off.

I built this whole setup on a "budget" with the goal of identifying unknown substances and to find out what is actually possible with a system that costs merely a fraction of a commercial instrument. I’ll walk you through the design considerations, challenges and limitations - and, of course, capabilities.

## What is Raman?

Now… what even is Raman?

When laser light hits a sample, almost everything that comes back is just the original laser color. That’s common scattering - called Rayleigh scattering - and it’s overwhelmingly bright, which makes it easily observable with the naked eye.

But a tiny fraction of photons actually does something special: they exchange a little bit of energy with the bonds that make up the molecule. That energy exchange shifts the color - or wavelength - of the incoming laser light slightly. This is called Raman scattering.

Those tiny shifts - and how intense they are respectively - encode the molecule’s vibrational structure. That’s the reason a Raman spectrum acts like a fingerprint. Every molecule uniquely interacts with a monochromatic light source, allowing spectra to be compared and matched against a known reference.

## Quick Overview

This is also where the challenge lies:

Raman is inherently weak. Think on the order of one in ten million photons undergoing that energy exchange. To efficiently separate these faint shifted photons, aggressive filters are absolutely integral. Otherwise your detector just sees the intense laser light, while your Raman signal vanishes underneath.

So the whole build is basically a constant battle against stray light and the excitation laser.

Now before diving into it, let's quickly go over the core components needed to make this work.

A 532nm green laser travels through a cleanup filter, hits a 45-degree dichroic beamsplitter and gets focused into the sample by a microscope objective. Then the scattered light comes back through the same objective, the dichroic separates the desired shifted light from the laser, a second long-pass filter cleans it up even more, and then a lens focuses what’s left into a spectrometer that turns it into a plot.

That’s the whole setup really.

## Components - Step-by-Step

Now let’s go step by step

Step one: the laser. (excitation source)
I’m using a cheap 532 nanometer "green" DPSS laser module with 50mW. It’s a great wavelength for DIY Raman because you can get a lot of Raman signal for the given power and shorter wavelengths are more efficient at stimulating Raman scattering.

But that comes with a cost: green excitation also tends to trigger more fluorescence in many organic materials, which will swamp your spectrum. So there’s an immediate tradeoff: sensitivity versus fluorescence.

Step two: laser cleanup. (bandpass filter)
Cheap lasers are not perfectly monochromatic - which means a single wavelength (a common green laser will oftentimes emit wavelengths in a range of say 10nm+- around 532nm). They can also have sidebands, mode hopping, and especially common in cheaper DPSS modules, leak significant amounts of infrared light that you can’t see - which is both dangerous and a problem because it can oversaturate the detector entirely. Most digital camera sensors have a pinkish "hot-mirror" built in front of the sensor for this exact reason.
So, to mitigate this, right after the laser, I use a bandpass filter to tighten up the wavelength. And if you’re using a very cheap DPSS module, you will also want an IR-blocking filter.

Step three: the heart of the configuration - the dichroic beamsplitter. (dichroic longpass mirror)
This is a long-pass dichroic mirror with a cut-on around 550nm, which is designed to be used at a 45 degree angle relative to the incoming light.
It works by strongly reflecting wavelengths below its cut-on point, while transmitting wavelengths above it.

So: the incoming green laser - at 532 nm - gets reflected down into the sample focusing objective.
But the returning scattered light from the sample contains two things at once:  
the original laser wavelength, and the Raman-shifted wavelengths that are slightly longer.
On the way back, the dichroic acts to send most of the laser light away, and it selectively transmits more of the Raman-shifted light, which sits at a longer-wavelength.

Step four: focusing and collection - the microscope objective.
I’m using a 20x infinity-corrected microscope objective.
This has two reasons.
First: focusing. The tighter you focus the laser spot, the higher the energy density on the sample, which ultimately translates to more Raman scattering.
Second: collection. In a so-called backscattering configuration, that same objective also serves to collect the scattered light to send it back along the same optical path.
Infinity-corrected objectives are convenient here because the returning light exits collimated, which facilitates the filtering and focusing downstream and theoretically allows for a more compact build.

Step five: the sample holder.
I’m using a quartz glass cuvette so I can measure both solids and liquids. Quartz glass is convenient, because it is chemically inert and excellent for optical applications. Though, cheap single-use plastic cuvettes also work.

To summarize so far: Laser is cleaned, selectively reflected and focused into the cuvette onto the sample, mainly Rayleigh scattering and a tiny fraction of Raman scattering occurs. Portions of the scattering that happen to hit the front of the microscope objective then get collected to be returned back through the dichroic mirror that now works to separate the signal that contains laser light and wavelength-shifted raman signal.

Step six: the second filter stage - because one filter isn't sufficient
Even after the dichroic, there’s still residual laser light and probably some stray reflections. Remember: Rayleigh is massively stronger than Raman.
So I use a second long-pass filter with the same cut-on around 550nm. This is not angled like the beamsplitter - it’s just a straight filter that further rejects anything at or below the laser wavelength and transmits the shifted light at longer wavelengths.

And yes, there is a compromise baked into this budget choice:
Because the filter cuts on around 550 nm, you lose the very low-shift region close to the laser line. This essentially limits the build to just the Stokes region above wavenumbers roughly above 600. In practice, you’re still capturing the important fingerprint region nicely - just the lower part of the spectrum is cut, as shifted wavelengths between the laser's 532nm and the filter's 550nm are effectively clipped from the spectrum.
That’s a deliberate tradeoff to keep this affordable.

Step seven: focusing into the spectrometer.
After filtering, the light is still collimated - or parallel. Now it needs to be focused into the spectrometer's input.
You can do that directly or you can use an optical fiber.
I’m using a fiber with a 200 micrometer core diameter. It’s convenient but it also makes alignment more sensitive, because now you’re trying to hit a tiny target with a focused spot.
So I use an adjustable mount for lateral positioning, and a small DIY translation stage to precisely dial in the focus.

## The Spectrometer 

Now, let's talk about the spectrometer.
This is a cost-efficient surplus unit commonly found on ebay for $200: the B&W Tek BTC100-2S. It might be older than I am but is probably still one of the more viable options in the price-range. Of course you can also DIY the spectrometer, but that seemed like a frustrating endeavour for someone like me, who had never dealt with optics before. 

In terms of specs it uses a Sony ILX51 linear CCD with roughly two thousand pixels, covers a 200nm range from 400 to 600 nanometers in its original configuration, and has a standard SMA905 fiber input. 
It comes with a 100 micrometer entry slit, with a longpass filter at 495nm in many cases - which doesn't cause problems for this project, so I left it in. It uses a 1800 lines per mm diffraction grating with a blaze at 550 nm and conveniently performs best in our region of interest.

Now the slit matters a lot. It’s one of the primary factors that dictate the spectral resolution: narrower slit gives narrower peaks and thus better separation. But it also starves the detector of light, which hurts signal-to-noise and leaves less room for alignment or collection imperfections.

So when you look at my spectra and notice some peaks blending together or they don't seem very distinct, that’s mainly due to the relatively wide slit.

The spectrometer is powered from 5 volts and communicates data via RS232-to-USB, which the software then plots as a spectrum.

## Why Raman Shift

At this point, we’ve successfully built the optical assembly. But, we still don't know the underlying idea of a Raman spectrum - why it uses wavenumber, opposed to wavelength, as it's commonly found in conventional spectra. This is what ultimately makes Raman measurements comparable, even when using a different wavelength laser.

How?
Because Raman shift directly represents the vibrational energy difference, independent of the excitation - or laser - wavelength.

The conversion is achieved by taking the reciprocal of the laser wavelength, subtracting the reciprocal of the measured wavelength, and then scaling it - that gives you the Raman shift in wavenumber as inverse centimeters.

To better illustrate, just remember the following:
A peak at 1000 cm-1 corresponds to the same molecular vibration whether you use a green laser, a red laser, or a near-infrared laser. That’s what makes Raman libraries possible.

## Challenges and Limitations 

Now, before we go deeper, I want to hit the second big obstacle of Raman - the thing that ruins a lot of first and subsequent attempts and poses a big limitation in identifiable samples:

Fluorescence.
Fluorescence is not Raman scattering. It happens when a molecule absorbs light, gets excited, and then re-emits light at longer wavelengths - so it undergoes a similar Stokes-shift as the Raman signal we're interested in. But: it’s usually broad, intense, and will - in many cases - completely drown out the spectrum.

That’s why many commercial Raman systems use 785 or 1064nm excitation - longer wavelengths tend to trigger less fluorescence.

But there’s a tradeoff again: Raman scattering efficiency drops strongly with longer wavelengths. Roughly speaking, it scales with the inverse fourth power of wavelength - which is why a 532 nm system can generate dramatically more Raman signal than a 1064 nm system at the same power.

With these constraints in mind and a small budget at my disposal, I went with 532nm for stronger Raman efficiency and lower cost optics. Accept that some samples will fluoresce and be difficult, and implement the filtering and stray-light control accordingly, so the system works well on a lot of non-fluorescent or mildly fluorescent molecules.

Now let’s talk about what actually makes this build succeed... or commonly fail.

The system is extremely sensitive to alignment - so angle and position - especially around the dichroic mirror and the fiber coupling. This is why kinematic tip-tilt mounts and finely adjustable stages are beneficial or at least dramatically facilitate getting any usable result at all. I use the KM100 mounts for the laser and the dichroic mirror, as even slight angle deviations will noticeably shift the cut-on wavelength of the dichroic and impair its performance.
On top of that, angled optics can shift the beam slightly due to the internal refraction of the material. So you require either lateral adjustment at the fiber input, or a compensation plate.

## Motorized Kinematic Mounts

To automate the alignment process, I dug through some papers and found one that did exactly this - even using the same kinematic mount. While I think the files weren't provided, the drawings helped me to recreate the setup. 

As described in the paper, I used two cheap stepper motors with drivers and an Arduino MEGA to motorize the tip and tilt mount for the laser. I also combined the Arduino code with a python script that provides convenient control of the positioning via a graphical interface. That just makes for a nicer experience than manually typing serial commands. 

The motors are wired and configured for micro-stepping, which theoretically allows for even finer adjustment - without having to reach into the box. This was somewhat cut short though by the slight play of the 3d-printed coupling that attaches to the stepper's shaft: so whenever I reversed the direction of the motor, some steps didn't actually move the adjustment screw. Since I was under the impression that I had to use a larger .6 nozzle for the carbon fibre PETG - which isn't the case - I had to work with slightly more clearance in the final parts. I used the .6 nozzle throughout the entire project so I plan to get back to iterating this further with the finer nozzle installed now. 

So this is still a work in progress but already a somewhat useful automation - despite the limitations. The vision is to eventually have a fully automated calibration protocol with all the parts motorized. 
But for now it'll have to suffice. 

## Practical Guidelines

Avoid dust, shiny surfaces, internal reflections and - again - alignment errors, as all of this creates stray paths that allow laser light to creep into your detector. 
To mitigate dust from contaminating the delicate and expensive filters, I built a slightly overpressurized glovebox from an IKEA storage box, two PC fans, a HEPA filter and some long-sleeve glove-inserts.
This worked well enough for prototyping but eventually you will want to incorporate the optical assembly into a light- and ingress-protected enclosure with integrated beam-dump and matte-black surfaces to reduce internal reflections. 

Also, choose a slit that matches your goals. For me, I kept the 100 micron slit, as it seems like a practical compromise. If you go narrower, peaks separate better, but you pay with longer integration times and potentially more noise, unless your system is built very efficient.

Now, let’s come back to that first paracetamol spectrum and I'll explain what you’re actually looking at.
Each peak corresponds to a vibrational mode - functional groups of the molecule stretching and bending. The overall pattern across the fingerprint region is mainly what makes identification possible.

And this is also where Raman becomes beautifully complementary to infrared spectroscopy.

While infrared absorption depends on changes in dipole moment, Raman depends on changes in polarizability. That means some vibrations that are weak in IR can be strong in Raman, and vice versa.
So in industry and field-testing, Raman and IR are often used in tandem, because their respective strengths and weaknesses 

## Cost & Parts

Now let’s talk about cost.
The core “essentials” in the build looks consist of:
The surplus spectrometer module, the cheap 532nm laser module, the 550nm dichroic mirror, the 550nm long-pass cleanup filter, the 20x microscope objective, the achromatic doublet - or plano-convex - focusing lens, sample cuvette and a couple of kinematic mounts.

That gets you into the ballpark of roughly 850 euros for the core components. Not included but integral to a functioning prototype are high-quality laser safety glasses from a reputable source - Aliexpress is absolutely not a reputable source for this!. 
Then you'll also need access to a 3d-printer, along with various parts like the precise cage rods, mounts, electronics and chemicals plus PPE for handling them.

So yes - this is still significant instrumentation money, but unlike any available Raman system, not in the tens-of-thousands range. The only reason it’s really possible at all is because we’re mixing professional filtering optics with used spectroscopy hardware and DIY'd and printed mechanics. If you are patient, you might be able to score some high-quality Raman-capable filters suitable for this on eBay, which could significantly reduce the cost down to just a couple hundred euros.

## Ideas for the Future

So where does this go from here?
Better filtering - like a steep notch filter - would let you measure closer to the laser line, but it’s expensive.
A different laser wavelength would reduce fluorescence for many samples but necessitates an entire new stack of optics, which make up most of the build cost.
An upgraded detector, narrower input slit or an entirely different spectrometer would increase resolution and sensitivity.
And on the software side, building a clean pipeline for baseline correction, cosmic spike removal, smoothing, calibration, and then library matching is where this becomes a truly usable identification tool.

## Conclusion

If you want to build one yourself, the project is fully documented as open hardware - with step by step instructions, parts lists, and additional notes. Visit DIYraman on Github or read the docs on docs.diyraman.com. The goal is to make Raman spectroscopy accessible to more people and interested tinkerers. 
On that note, I also highly recommend checking out the OpenRaman-project. It's a brilliant resource, if you want to build a more capable high-performance Raman spectrometer yourself - with the benefit of it being designed by an actual optical engineer. 

If you’re now thinking “damn, I really want one myself” - perfect. That’s the whole point.

Just keep in mind to tinker safely: treat lasers with respect, wear proper protective equipment, and never underestimate the dangers of lasers and their reflections. Your eyes will be forever grateful.

In the future, I will get into surface-enhanced Raman spectroscopy, which uses nanoparticles to dramatically increase the occurrence of Raman scattering. This allows you to detect molecules even in trace quantities and concentrations.
I'm also currently testing the next, improved iteration, that is more compact and significantly cuts the complexity of the build. 

Alright, thanks for watching, I hope you learned something new and enjoyed the video. For more projects, subscribe and let me know what you think in the comments. Bye!

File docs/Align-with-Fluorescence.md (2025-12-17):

# Aligning with Fluorescence

A dilute Rhodamine B solution is the **standard alignment sample** for the Raman optical assembly: if you cannot get a strong Rhodamine B signal, you will not be able to acquire a Raman signal from anything else.   

Laser shining into glass filled with fluorescent rhodamine b solution  
*Oversaturated Rhodamine B solution excited with a laser. The bright orange path reveals the laser's beam path.*

**The fluorescent reference cuvette is used to:**
- **Visualise the laser** – the beam path and focal point become clearly visible in orange.  
- **Verify the optics** – confirms that objective, mirrors and coupling are aligned.  
- **Check the filters** – the 532 nm line should be strongly suppressed while orange/red fluorescence passes.

> [!INFO] Reminder  
> This uses the same printed cuvette holder as the [Core-Assembly](Core-Assembly.md#Sample%20Assembly).  
> For alignment you **do not** need a calibrated standard: a faintly pink, transparent solution is enough. Concentration only needs to be **roughly** in the right range.

---

## Parts and Materials

> [!EXAMPLE] Visit the complete Bill of Materials
> Everything you will need, both printed parts and sourced parts, along with their cost and supplier, can be viewed in the dedicated [BOM](../bom/BOM.md)!

### Sourced parts

| Qty | Name | Model / Spec | Notes |
| --- | --- | --- | --- |
| 1x  | Quartz Cuvette | Any | Same as [Basic Raman Optical Assembly - Sample Assembly](Core-Assembly.md#Sample%20Assembly) |
| 1x  | Fluorescent dye | Rhodamine B (*CAS: 81-88-9*), 5g | Any strong fluorescent material with excitation at around the laser's wavelength (532 nm) |
| - | Pipette or syringe (1–5 mL) | | |
| - | Distilled / deionised water | | |
| - | PPE (gloves, goggles, lab coat) | | |

### Printed parts

| Qty | Part name (.stl) | Used in |
| --- | --- | --- |
| 1x  | `Kuvettecase_Top` | Identical used: [Sample Assembly](Core-Assembly.md#Sample%20Assembly) |
| 1x  | `Kuvettecase_Bottom` | Identical used: [Sample Assembly](Core-Assembly.md#Sample%20Assembly) |

---

## Preparation – Step-by-Step with Images

Rhodamine B solutions slowly degrade and can adsorb onto container and cuvette walls. For alignment it is best to prepare a small batch fresh and use it over a few days (stored dark and cool).

If you own multiple cuvettes, **designate one** as the “fluorescence cuvette” to avoid trace contamination of later Raman samples.

> [!DANGER] Hazardous substance – permanent staining and eye damage  
> Rhodamine B can permanently and irreversibly stain skin, work surfaces and fabrics, and is harmful to eyes and mucous membranes.  
> - [Read the SDS](https://www.sigmaaldrich.com/DE/fr/sds/sigma/r6626) from your supplier before use.  
> - Always wear **safety goggles** and **nitrile/latex gloves**.  
> - Work on an easy-to-clean or disposable surface.  
> - Wipe spills immediately with damp disposable wipes.  
> - Wash hands and forearms thoroughly after handling, even when wearing gloves.  
> - Never touch eyes or contact lenses while working with the dye.

### 1. Make a rough stock solution (by eye)

This is sufficient for almost all users and does not require a scale.

Preparing an initial Rhodamine B stock solution

1. Fill a small glass container with about **50 mL distilled water**.

Adding small amounts of Rhodamine B until faintly pink

2. Lightly tap a **tiny amount** of Rhodamine B powder into the water – you want just a trace of dust until faint pink streaks appear.

Homogenising the solution

3. Swirl gently until the dye is fully dissolved. Aim for a **transparent light pink** solution – not opaque or dark.

Adjusting the volume if undissolved particles are visible

4. If solid particles remain, add a bit more water and swirl again until the solution looks homogeneous.  
   This “pink stock” is roughly in the **0.1–1 mM** range and will be diluted further.

> [!TIP] Optional precise stock (1 mM)  
> - Weigh **4.8–5.0 mg** Rhodamine B.  
> - Dissolve in **10 mL** water in a volumetric flask or cylinder → **1 mM stock**.  
> - A 1:100 dilution (0.1 mL stock + 9.9 mL water) gives a **10 µM working solution** within the 5–20 µM range.

---

### 2. Dilute to working concentration

Diluting the stock to a working solution

**Simple method (Single Container):**
1. Pour off some of the solution and top up with fresh water.
2. Repeat until you reach the desired dilution.

**Stock method (Two Containers):**
1. Take a small volume of your stock (e.g. **1 mL**).  
2. Add it to **20–50 mL** of clean water (≈ 1:20–1:50 dilution).  
3. Gently mix.  

> [!TIP] Visual rule of thumb  
> - Cuvette glows bright orange → good range.  
> - Everything looks like an opaque orange block, focus disappears → too concentrated → add water.  
> - Barely any fluorescence → too dilute → add a little more stock solution.

---

### 3. Fill the cuvette

Filling the cuvette with Rhodamine B solution

1. Use a pipette/syringe to fill the cuvette with the working solution.

Avoid overfilling the cuvette

2. Fill only as much as needed to **cover the circular optical window** in the printed holder (≈ ½–⅔ full).  
3. If your cuvette has a cap, close it carefully to avoid drips.

---

### 4. Insert the cuvette into the printed holder

Inserting the cuvette into the printed base

1. Slide the filled cuvette into `Kuvettecase_Bottom`.

Seating the cuvette with light pressure

2. Gently press it down so it sits fully against the reference surface in the printed base.  
   - If the cuvette has two clear faces, make sure they face the laser input and collection optics.

Closing the cuvette housing

3. Slide `Kuvettecase_Top` over the base to secure the cuvette.

> [!WARNING] Keep upright  
> Always transport the assembled cuvette **upright**. Spilled Rhodamine B inside the optical assembly is difficult to remove and can permanently stain components.

---

## Optional: How to use for Alignment

Once the cuvette is mounted in the [Sample Assembly](Core-Assembly.md#Sample%20Assembly):

1. Place the cuvette holder at the objective focus (inside the cuvette, focusing its contents).  
2. Switch on the laser (at low power, if possible).  
3. From the side, verify a bright orange beam path and a clearly defined focus inside the cuvette.  
4. In the acquisition software you should see:  
   - A strong, broad fluorescence band at longer wavelengths (Stokes side).  
   - A heavily suppressed 532 nm laser line if longpass filters are correctly installed. 
1. Adjust mirror angles and focus until the fluorescence signal is strong and stable, aiming for the highest intensity value possible.

> [!TIP] Quick troubleshooting  
> - **No signal** → beam misses the cuvette or hits the plastic holder.  
> - **Strong laser line, weak fluorescence** → check filter orientation and Rhodamine B concentration.  
> - **Spectrum drifting / fading** → reduce laser power or prepare a fresh solution.

---

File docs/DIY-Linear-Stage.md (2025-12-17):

# DIY Linear Stage

Linear translation stage – assembled

Build a compact linear translation stage for fine axial adjustment of the focusing optics in the [Full-Build](Full-Build.md).

This stage uses:

- Two smooth metal rods as linear guides  
- A micrometer screw for precise movement  
- Two compression springs to pre-load the moving stage  

The design is simple to print and tune, and accurate enough to focus the final lens or fibre position onto the spectrometer input.

> [!NOTE] Where this stage is used  
> In the recommended build path, this translation stage sits underneath the **Focusing Assembly** [Focusing Assembly](Core-Assembly.md#Focusing%20Assembly) in the [Full-Build](Full-Build.md).  
> It is **not** required for the [Core-Assembly](Core-Assembly.md) but strongly recommended for comfortable fine focus adjustment.

---

## Parts and Materials



> [!EXAMPLE] Visit the complete Bill of Materials
> Everything you will need, both printed parts and sourced parts, along with their cost and supplier, can be viewed in the dedicated [BOM](../bom/BOM.md)!

### Sourced parts

| Qty | Name | Model / Spec | Notes |
| --- | --- | --- | --- |
| 1x  | Micrometer screw | ~10-15 mm travel | With mounting nut/collar |
| 2x  | Guide Rod ⌀ 6 mm, 55 mm | Any, [ER Assembly Rods for 30 mm Cage Systems](https://www.thorlabs.de/newgrouppage9.cfm?objectgroup_ID=4125) | Ideally for optical applications (tight tolerances) |
| 2x  | Compression spring | ⌀ ≥ 6 mm | Stiffness chosen for light pre-load |
| 4x  | M3.5 screw + washer + nut | ~12 mm length | |

### Printed parts

| Qty | Part name (.stl) | Print preview |
| --- | --- | --- |
| 1x  | `LinearStage_Base` |  |
| 1x  | `LinearStage_Stage` |  |
| 1x  | `LinearStage_Frontplate` |  |
| 1x  | `LinearStage_L-Bracket`  |   |

---

## Preparing the Printed Parts

Good rod fit is critical for smooth and repeatable motion. Before full assembly, verify and tune the fit of the rods in both the base and the moving stage.

### Step 1 – Base

For the base, the rods should press in firmly and not move once installed.

1. Measure the rod diameter with digital callipers to confirm ~⌀ 6.0 mm.  
2. Push each rod all the way through the rod holes in `LinearStage_Base`:



   - You should feel noticeable, even resistance as the rod enters the holes.  
   - Once inserted, the rods should not wobble or rattle in the base.

3. If the rods **do not fit at all**:  
   - Lightly sand the inside of the rod holes with rolled-up sandpaper.  
   - Clean the dust and test the fit again. Repeat until the rod can be pressed through with firm pressure.

> [!WARNING] Sanding fibre-reinforced filaments  
> When sanding PETG-CF or similar materials, wear appropriate PPE (at least a particle mask). Fine fibres and plastic dust can be harmful if inhaled, especially with repeated exposure.

4. If the rods have **visible play**:  
   - First confirm that the rods are actually ⌀ 6.0 mm (cheap rods can vary).  
   - If rods are correct, consider slightly shrinking the holes in your CAD/source file or using slicer hole compensation to reduce the effective hole size, then re-print the base.

> [!TIP] Print seam settings  
> If your slicer allows it, use **random seam positioning** for this part. This avoids a single pronounced seam ridge inside the hole that can interfere with accurate rod fit.

---

### Step 2 – Stage

The stage must slide smoothly on the rods with minimal play.

1. Insert a rod into one of the holes in `LinearStage_Stage` and push it through:

   

   - The rod should move with slight resistance but **not** bind or jam.  
   - A small amount of stiffness is acceptable and often improves after some movement or light lubrication.

2. Repeat for the second rod hole. Both rods should slide similarly.

3. If the fit is **too tight or jerky**:  
   - Very lightly sand the inside of the rod holes.  
   - Clean the dust and test again.

4. If the fit is **very loose** and the stage can tilt on the rods, consider:  
   - Reducing the hole size in the source file or with slicer hole compensation, then re-printing, or  

> [!INFO] Clean after sanding  
> After sanding, remove dust with compressed air or a vacuum and wipe the parts with a damp paper towel. Loose particles can increase friction and wear over time.

---

## Assembly

Exploded view and motion of the linear stage

Once the printed parts are tuned for proper rod fit, you can assemble the stage.

### Step 3 – Install the micrometer screw

1. Insert the **micrometer head** into the central opening of `LinearStage_Base` from the front.  
2. Use the nut supplied with the micrometer to secure it against the base.  
3. Make sure that:  
   - The micrometer axis is aligned with the central recess in the `LinearStage_Stage`. 
   - The micrometer body does not collide with the rods or springs over the full range of motion.

> [!TIP] Avoid overtightening the micrometer nut  
> Tighten only until the micrometer body does not move when you try to rotate or pull it by hand. Over-tightening can warp the printed base or damage the micrometer threads.

---

### Step 4 – Install rods and stage

Assembly animation – base, rods, stage, springs

1. Insert both ⌀ 6 mm rods from the **same side** of the `LinearStage_Base`. Push them approximately **one third** of the way in.  
2. Position the `LinearStage_Stage` so that its central recess faces the **tip of the micrometer screw**.  
3. Carefully align the two rod holes in the stage with the rods and slide the stage onto the rods.  
4. Make sure the micrometer tip sits in the central recess of the stage or contacts the intended push surface.  
5. Push the rods further through the base and stage until they protrude slightly on the opposite side, leaving room for the springs.

> [!WARNING] Do not force misaligned rods  
> If the rods do not slide through the stage easily, remove the stage and check alignment. Forcing misaligned rods can crack the printed part or bend the rods.

---

### Step 5 – Add the springs

1. Slide one compression spring onto each rod.  
   - It is often easiest to place the spring on the rod first and then compress it into the recess between base and stage.  
2. Seat each spring so it sits **between the base and the stage** in the intended recess, providing a light pushing force against the stage.  
3. Push the rods fully into the base until:  
   - The springs are slightly pre-loaded (compressed a few millimetres), and  
   - The rods are fully seated in both ends of the base.
4. Gently turn the micrometer screw to move the stage through its travel:  
   - The stage should move smoothly with no sudden jumps.  
   - There should be minimal backlash (lost motion) when reversing direction.  
   - The springs should stay seated and not buckle.
5. Apply a **small amount of lubricant** to the rods if needed to improve the feel of the motion.

---

### Step 6 – Optional: Frontplate 

1. Align `LinearStage_Frontplate` with the corresponding holes on the front of the `LinearStage_Base`.  
2. Fix the front plate with four suitable screws (e.g. M3.5 with washers and nuts), tightening evenly.  
3. Verify that:  
   - The rods remain parallel and properly seated.  
   - The stage still moves freely over the desired range.  
   - The micrometer tip remains correctly engaged with the stage.

The front plate increases stiffness at the front end of the rods and reduces the risk of flex when the stage changes direction.

---

## Mounting to the Raman Baseplate

In the **Full Raman Optical Assembly**, this stage is mounted beneath the focusing optics module.

1. Identify the mounting pattern for the translation stage on your Raman baseplate (see [Full-Build](Full-Build.md)).  
2. Disassemble the desired `Defaultholder` that holds the focusing lens by sliding it off the assembly rods.
3. Use four screws to mount the optic holder to the stage.
4. Place the assembled linear translation stage on the baseplate and align the mounting holes.  
5. Use four screws and nuts to fasten the stage - using an L-bracket - to the baseplate.  
6. Tighten all screws evenly, then verify that the stage still moves smoothly, no screw heads interfere, and that the micrometer remains accessible from the desired side.

> [!NOTE] Orientation on the baseplate  
> Mount the stage so that the micrometer is accessible from the front or side you find most convenient when adjusting. The exact orientation is not critical as long as the axis of motion aligns with the optical axis of the focusing optics.

---

## Design Notes and Tuning

For this design, part of the micrometer’s total travel is intentionally used to:

- Pre-load the springs (so the stage is always pressed firmly against the micrometer tip), and  
- Avoid fully compressing the springs at the end of travel (to keep motion smooth and predictable).

In practice, the **useful travel** of the stage is around **5 mm**, which is more than sufficient for fine focus adjustment of the final lens (or fibre input) in the [Full-Build](Full-Build.md).

The spring pre-load:

- Reduces backlash when reversing micrometer direction  
- Keeps the stage under constant tension  
- Improves repeatability of small position changes

> [!NOTE] Tuning the feel  
> You may need to experiment with different springs and pre-load amounts.  
> - Too little tension → noticeable backlash and vague response when reversing.  
> - Too much tension → high torque required on the micrometer, especially near travel limits.  
> Aim for a point where the stage moves smoothly and repeatably with moderate turning force.

---

## Related

- [Build an Overpressure Glove Box](Dustproof-Workspace.md)  
- [Core-Assembly](Core-Assembly.md)  
- [Full-Build](Full-Build.md)

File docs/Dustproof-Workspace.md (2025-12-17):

# Dustproof Workspace

Overview of the overpressure glove box

Build a simple overpressure glove box to keep dust and airborne contaminants away from your Raman optics while you mount and align sensitive components such as the dichroic beamsplitter and longpass filter.

In this configuration, two fans push air **into** the box through a HEPA filter. The slight overpressure forces air out through any small leaks or gaps, so dust-laden air from the room cannot enter the enclosure.

> [!NOTE] Why overpressure?
> - **Sealed box:** Better than working in open air, but leaks and each opening event can let dust in.
> - **Underpressure (negative pressure):** Used when you must contain hazardous materials - all inlet and outlet paths must be carefully filtered.
> - **Overpressure (this design):** Easier to build for DIY use. Incoming air is filtered once; leaks push clean air *out* instead of pulling dirty air *in*.

This glove box is sized around an off‑the‑shelf IKEA SAMLA box but the concept works with any similar transparent container that can take cut‑outs for fans, filter and glove ports.

---

## Parts and Materials

> [!EXAMPLE] Visit the complete Bill of Materials
> Everything you will need, both printed parts and sourced parts, along with their cost and supplier, can be viewed in the dedicated [BOM](../bom/BOM.md)!

### Sourced parts

| Qty | Name | Model / Spec | Notes |
| --- | --- | --- | --- |
| 1x | Storage box | [IKEA SAMLA](https://www.ikea.com/de/en/p/samla-box-with-lid-transparent-s99440774/), transparent, <br>57×39×42 cm | Any similar box works, separate lid that forms tight seal is ideal. |
| 1x | HEPA filter | [IKEA UPPATVIND](https://www.ikea.com/de/en/p/uppatvind-filter-for-particle-removal-90551498/) | Any HEPA / fine dust filter of similar size works. Higher filtration = more pressure drop. |
| 2x | PC fan | Any, 120 mm PC fan | 12V DC fans. Check current draw and airflow rating. |
| 2x | Gloves | Any, long‑sleeved chemical or dishwashing gloves | Choose gloves long enough to reach all areas inside the box. |
| 14x | M4 screw + nut | Hex socket head cap screw | Mixture of lengths below. |
| 4x<br>4x<br>2x<br>4x | | M4 × 12 mm<br>M4 × 16 mm<br>M4 × 20 mm<br>M4 × 65 mm | |

### Printed parts

| Qty | Part name (.stl) | Used in | Print preview |
| --- | --- | --- | --- |
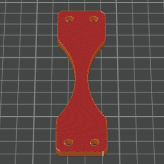
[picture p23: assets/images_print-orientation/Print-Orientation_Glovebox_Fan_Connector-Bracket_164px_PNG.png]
| 1x  | `Fan_Connector‑Bracket` | Fan / filter assembly |  |
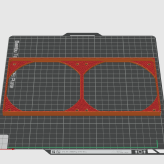
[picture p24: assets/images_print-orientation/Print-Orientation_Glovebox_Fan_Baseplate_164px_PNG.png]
| 1x  | `Fan_Baseplate` | Fan / filter assembly |  |
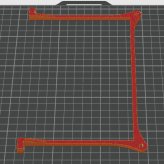
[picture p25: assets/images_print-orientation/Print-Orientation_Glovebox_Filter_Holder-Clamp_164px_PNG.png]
| 2x  | `Filter_Holder‑Clamp` | Fan / filter assembly |  |
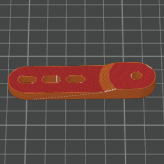
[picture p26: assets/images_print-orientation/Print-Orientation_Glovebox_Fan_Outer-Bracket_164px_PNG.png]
| 4x  | `Fan_Outer‑Bracket` | Fan / filter assembly |  |
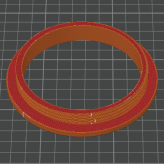
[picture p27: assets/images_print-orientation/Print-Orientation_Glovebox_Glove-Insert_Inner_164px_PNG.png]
| 2x  | `Glove‑Insert_Inner` | Glove ports |  |
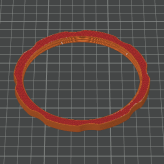
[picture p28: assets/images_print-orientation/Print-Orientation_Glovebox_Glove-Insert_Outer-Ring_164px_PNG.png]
| 2x  | `Glove‑Insert_Outer‑Ring` | Glove ports |  |
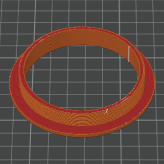
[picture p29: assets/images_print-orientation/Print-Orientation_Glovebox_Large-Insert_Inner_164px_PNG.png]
| 1x  | `Large‑Insert_Inner` | Large service port |  |
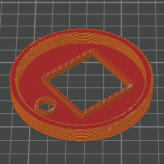
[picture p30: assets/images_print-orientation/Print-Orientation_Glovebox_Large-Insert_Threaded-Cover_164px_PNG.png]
| 1x  | `Large‑Insert_Threaded‑Cover` | Large service port |  |
| 1x  | `Large‑Insert_Outer‑Cover‑Open` | Large service port |  |
| 1x  | `Large‑Insert_Outer‑Cover‑Closed` | Large service port |  |
| 1x  | `Cable‑Insert_Inner` | Cable / feedthrough port |  |
| 1x  | `Cable‑Insert_Nut` | Cable / feedthrough port |  |
| 1x  | `Cable‑Insert_Cover` | Cable / feedthrough port |  |

### Notes for printing

> [!TIP] Suggested print settings  
> - Material: PETG-CF or ABS recommended for best strength.  
> - Layer height: 0.2 mm.  
> - Infill: 30–40 % gyroid or cubic.  
> - Perimeters: ≥ 3 perimeters (walls) for brackets and inserts.  
> - Colour: Any - black preferred; opaque colours reduce stray light inside the box.

All parts are designed to print without support on a typical 0.6 mm nozzle - 0.4 is even better but sub-optimal for abrasive PETG-CF. For parts that clamp the box wall (fan brackets and glove inserts), ensure accuracy of holes and circular cutouts. If your printer tends to undersize holes, you can slightly scale the part in X/Y or adjust hole compensation in your slicer.

---

## Instructions

### 1. Preparing the box

Transparent plastic container with lid and cutouts – final result

In this section you mark and cut all openings in the box and lid: the fan / filter opening, glove ports, cable feedthrough and large service port.

#### Step 1.1 – Marking the cutouts

Top template for marking fan and filter opening

> [!NOTE] Printable template  
> An A4 PDF template is provided in the repository. Print at **100 % scale (no scaling)** and check at least one dimension with a ruler before cutting.

1. Clean the outer surfaces of the box and lid so masking tape will adhere.  
2. On the **top** of the box, tape the printed template in place and align it with the centre of the lid as shown in the PDF / images.  
3. Mark the following on the box with a non‑permanent marker:  
   - **Main fan/filter opening:** 250 × 195 mm rectangular cutout.  
   - **Fan mounting holes:** 4 × holes at the corners for M4 screws (drill 4 mm).  
4. On the **front side of the lid**, mark two circular openings for the glove ports:  
   - **Glove inserts:** 2 × circles, 96 mm diameter each.  
5. On the **left side of the box**, mark:  
   - **Large insert:** 1 × circle, 72 mm diameter.  
   - **Cable insert:** 1 × hole, 12 mm diameter.

Top of the box with rectangular cutout and four drilled holes for fan/filter assembly

Front of the lid with two circular cutouts for glove inserts

Left side of the box with one large circular cutout and one small hole

> [!WARNING] Check dimensions twice  
> Before cutting, verify all positions and diameters with the corresponding 3D‑printed inserts. The parts should cover a few millimetres of plastic around each cutout for a good seal.

#### Step 1.2 – Cutting and drilling

Cutting the openings in the plastic box

1. Drill a starter hole inside each closed shape (rectangles / circles) using a drill bit sized for your cutting tool (e.g. 6–8 mm).  
2. For the **rectangular top opening**, insert a fine‑tooth jigsaw blade or rotary tool and carefully cut along the marked lines.  
3. For the **circular openings**, use a hole saw, step bit, or carefully cut along the line with a rotary tool.  
4. Drill the **M4 mounting holes** (4 mm diameter) at the marked fan / filter positions.  
5. Deburr all edges with a file or fine sandpaper so the printed parts sit flush.

Deburring and finishing the cutouts

> [!WARNING] Cutting plastic safely  
> - Wear safety glasses and a dust mask.  
> - Clamp the box securely so it cannot move while cutting.  
> - Work slowly to avoid cracking the plastic.

---

### 2. Fan assembly

Printed fan baseplate and brackets with fan

In this step you assemble the fan on its printed baseplate and outer brackets.

#### Step 2.1 – Mount the fan to the baseplate

Attaching the fan to the printed baseplate

1. Place the `Fan_Baseplate` on your workspace with the flat side down.  
2. Orient the 120 mm fan so that it will **blow air into the box** when mounted (the airflow arrow on most fans should point towards the box).  
3. Align the fan’s mounting holes with those in the `Fan_Baseplate`.  
4. Use four suitable screws (e.g. M4 × 12 mm) to fasten the fan to the baseplate.

> [!TIP] Fan orientation  
> If your fan has a label and struts on one side: usually the **strut side** is the air outlet. For this design, the outlet should face **towards the box**.

#### Step 2.2 – Attach outer brackets

Adding outer brackets and connector bracket

Outer brackets detail
Outer brackets from different angle
Assembled fan module with brackets

1. Attach the `Fan_Connector‑Bracket` and `Fan_Outer‑Bracket`s to the `Fan_Baseplate` according to the exploded view in the project files.  
2. Use M4 screws and nuts where provided to secure the brackets.  
3. Double‑check that all parts sit flat and that nothing interferes with the fan blades.

---

### 3. Mounting fan and filter on the box

Box with cutouts ready for mounting fan and filter
Test‑fitting the fan module on the top opening

In this step you clamp the HEPA filter and the fan assembly to the top of the box.

#### Step 3.1 – Position the HEPA filter

Positioning the HEPA filter over the top cutout
Aligning filter edges and mounting holes

1. Place the box so that the top opening faces upwards.  
2. Lay the HEPA filter on the **inside** of the lid or box top so it completely covers the 250 × 195 mm rectangular cutout.  
3. Align the edges so that the filter frame sits evenly and there is enough overlap for a good seal.  
4. The filter should stay in place on its own, sitting on the outer lip.

Placing printed filter holder clamps inside the box
Filter clamped with printed parts

5. Position the `Filter_Holder‑Clamp` parts on the inside, over the filter frame, aligned with the drilled M4 holes.

#### Step 3.2 – Clamp fan and filter together

Inserting long screws through fan, lid and filter clamps
Tightening nuts to clamp filter and fan
View from inside showing filter clamped
Fan and filter fully mounted – outside view
Fan and filter fully mounted – inside view
Fan and filter assembly close‑up

1. Place the assembled fan module on the **outside** of the box, over the rectangular opening.  
2. Align the fan bracket holes with the drilled M4 holes and the `Filter_Holder‑Clamp`s inside the box.  
3. Insert four long M4 screws (e.g. M4 × 65 mm) from the outside through: fan bracket → box lid → filter clamp.  
4. On the inside, place M4 nuts on each screw and tighten them evenly until the filter and fan are clamped firmly and the plastic deforms only slightly.  
5. Verify that the fan blades spin freely and that the filter frame is compressed all around for a good seal.

> [!WARNING] Do not overtighten  
> Excessive torque on the screws may crack the box wall or warp the filter frame. Tighten only until nothing moves when pushed gently.

---

### 4. Box inserts (cable and service ports)

Overview of printed inserts installed in the side wall

This section covers the smaller side ports: a cable feedthrough and a larger service port (65–72 mm insert).

#### Step 4.1 – Cable insert

Cable insert – inside view
Cable insert – parts and assembly
Cable insert – outside view with nut
Cable insert – cover installed

1. From the **inside** of the box, insert the `Cable‑Insert_Inner` through the 12 mm cable hole.  
2. From the **outside**, thread the `Cable‑Insert_Nut` onto the protruding part and hand‑tighten until the box wall is clamped firmly between the two parts.  
3. When no cables are routed, close the port with the `Cable‑Insert_Cover`.  
4. To route a cable, remove the cover, feed the cable through, and reseal as well as possible with tape or a custom drilled cover.

#### Step 4.2 – Large service insert (65–72 mm)

Large service insert – inner part
Large service insert – outer open cover
Large service insert – outer closed cover
Large service insert fully assembled

1. From the **inside** of the box, place the `Large‑Insert_Inner` into the 72 mm side opening.  
2. From the **outside**, align the appropriate outer cover (`Large‑Insert_Outer‑Cover‑Open` or `Large‑Insert_Outer‑Cover‑Closed`) and fasten it to the inner part according to the design (screws or bayonet lock).  
3. Use the **closed cover** when maximum sealing is required.  
4. Use the **open cover** variant to pass larger objects in or out of the box while keeping the opening controlled and easy to re‑seal.

---

### 5. Gloves

Glove ports and gloves mounted in the lid

#### Step 5.1 – Choosing gloves

Select gloves that:  
- Are **long enough** to reach all areas in the box.  
- Have a **cuff diameter** compatible with the `Glove‑Insert_Inner` and `Glove‑Insert_Outer‑Ring`.  
- Are made from a material resistant to any solvents or chemicals you expect to use (e.g. nitrile or thicker dishwashing gloves).

> [!TIP] Test fit one glove first  
> Before assembling both ports, test the fit with one glove and adjust how far you roll the cuff to achieve a good seal and comfortable reach.

#### Step 5.2 – Mounting the glove screw‑on inserts

Mounting glove on inner insert
Clamping glove with outer ring
Glove insert fully mounted in lid

1. Turn the lid so the **inside** faces up. Insert the `Glove‑Insert_Inner` into one of the 96 mm circular openings from the inside.  
2. Slide the glove cuff over the inner insert so that ~3–5 cm of the glove overlaps the flange.  
3. Place the `Glove‑Insert_Outer‑Ring` over the glove from the outside of the lid and push it onto the inner insert, clamping the glove material in between.  
4. Ensure the glove is clamped evenly all around and cannot be pulled out by gentle force.  
5. Repeat the procedure for the second glove port.

> [!WARNING] Do not overstretch the glove cuff  
> Overstretching can lead to tears. If the glove material feels too tight, choose a larger insert size or a different glove model.

---

### 6. Wiring and first test

#### Step 6.1 – Connect fans to the power supply

> [!DANGER] Mains safety  
> If you need to modify a mains‑powered supply, only do so if you are qualified to work with mains voltages. Otherwise use an off‑the‑shelf, enclosed 12 V supply and keep all mains wiring outside the glove box.

1. Connect both 120 mm fans **in parallel** to the 12 V DC output of your power supply:  
   - All positive (red) wires together to **+12 V**.  
   - All negative (black) wires together to **GND**.  
2. If you want adjustable airflow, you can add a simple fan controller or a PWM speed control module between the supply and the fans.  
3. Route the fan power cable along the box by taping it or at least make sure it won't accidentally get into the fan blades.

#### Step 6.2 – Check overpressure and leaks

1. Close the lid and ensure all ports (large insert, cable insert, glove rings) are fully assembled.  
2. Turn on the fans. After a few seconds, the lid may bulge slightly as pressure builds.  
3. Hold a thin strip of tissue paper or incense stick **near** (not inside) suspected leak points around the lid and inserts: the strip should blow **outwards**, not be sucked in.  
4. If you detect inward leaks, check and re‑seat the inserts or consider adding sealing tape.

Your overpressure glove box is now ready to use for clean assembly of the Raman optical components.

---

## Continue reading

- [Core-Assembly](Core-Assembly.md)  
- [DIY-Linear-Stage](DIY-Linear-Stage.md)

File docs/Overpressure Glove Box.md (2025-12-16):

# Dustproof Workspace

Overview of the overpressure glove box

Build a simple overpressure glove box to keep dust and airborne contaminants away from your Raman optics while you mount and align sensitive components such as the dichroic beamsplitter and longpass filter.

In this configuration, two fans push air **into** the box through a HEPA filter. The slight overpressure forces air out through any small leaks or gaps, so dust-laden air from the room cannot enter the enclosure.

> [!NOTE] Why overpressure?
> - **Sealed box:** Better than working in open air, but leaks and each opening event can let dust in.
> - **Underpressure (negative pressure):** Used when you must contain hazardous materials - all inlet and outlet paths must be carefully filtered.
> - **Overpressure (this design):** Easier to build for DIY use. Incoming air is filtered once; leaks push clean air *out* instead of pulling dirty air *in*.

This glove box is sized around an off‑the‑shelf IKEA SAMLA box but the concept works with any similar transparent container that can take cut‑outs for fans, filter and glove ports.

---

## Parts and Materials

> [!EXAMPLE] Visit the complete Bill of Materials
> Everything you will need, both printed parts and sourced parts, along with their cost and supplier, can be viewed in the dedicated [BOM](../bom/BOM.md)!

### Sourced parts

| Qty | Name | Model / Spec | Notes |
| --- | --- | --- | --- |
| 1x | Storage box | [IKEA SAMLA](https://www.ikea.com/de/en/p/samla-box-with-lid-transparent-s99440774/), transparent, <br>57×39×42 cm | Any similar box works, separate lid that forms tight seal is ideal. |
| 1x | HEPA filter | [IKEA UPPATVIND](https://www.ikea.com/de/en/p/uppatvind-filter-for-particle-removal-90551498/) | Any HEPA / fine dust filter of similar size works. Higher filtration = more pressure drop. |
| 2x | PC fan | Any, 120 mm PC fan | 12V DC fans. Check current draw and airflow rating. |
| 2x | Gloves | Any, long‑sleeved chemical or dishwashing gloves | Choose gloves long enough to reach all areas inside the box. |
| 14x | M4 screw + nut | Hex socket head cap screw | Mixture of lengths below. |
| 4x<br>4x<br>2x<br>4x | | M4 × 12 mm<br>M4 × 16 mm<br>M4 × 20 mm<br>M4 × 65 mm | |

### Printed parts

| Qty | Part name (.stl) | Used in | Print preview |
| --- | --- | --- | --- |
| 1x  | `Fan_Connector‑Bracket` | Fan / filter assembly |  |
| 1x  | `Fan_Baseplate` | Fan / filter assembly |  |
| 2x  | `Filter_Holder‑Clamp` | Fan / filter assembly |  |
| 4x  | `Fan_Outer‑Bracket` | Fan / filter assembly |  |
| 2x  | `Glove‑Insert_Inner` | Glove ports |  |
| 2x  | `Glove‑Insert_Outer‑Ring` | Glove ports |  |
| 1x  | `Large‑Insert_Inner` | Large service port |  |
| 1x  | `Large‑Insert_Threaded‑Cover` | Large service port |  |
| 1x  | `Large‑Insert_Outer‑Cover‑Open` | Large service port |  |
| 1x  | `Large‑Insert_Outer‑Cover‑Closed` | Large service port |  |
| 1x  | `Cable‑Insert_Inner` | Cable / feedthrough port |  |
| 1x  | `Cable‑Insert_Nut` | Cable / feedthrough port |  |
| 1x  | `Cable‑Insert_Cover` | Cable / feedthrough port |  |

### Notes for printing

> [!TIP] Suggested print settings  
> - Material: PETG-CF or ABS recommended for best strength.  
> - Layer height: 0.2 mm.  
> - Infill: 30–40 % gyroid or cubic.  
> - Perimeters: ≥ 3 perimeters (walls) for brackets and inserts.  
> - Colour: Any - black preferred; opaque colours reduce stray light inside the box.

All parts are designed to print without support on a typical 0.6 mm nozzle - 0.4 is even better but sub-optimal for abrasive PETG-CF. For parts that clamp the box wall (fan brackets and glove inserts), ensure accuracy of holes and circular cutouts. If your printer tends to undersize holes, you can slightly scale the part in X/Y or adjust hole compensation in your slicer.

---

## Instructions

### 1. Preparing the box

Transparent plastic container with lid and cutouts – final result

In this section you mark and cut all openings in the box and lid: the fan / filter opening, glove ports, cable feedthrough and large service port.

#### Step 1.1 – Marking the cutouts

Top template for marking fan and filter opening

> [!NOTE] Printable template  
> An A4 PDF template is provided in the repository. Print at **100 % scale (no scaling)** and check at least one dimension with a ruler before cutting.

1. Clean the outer surfaces of the box and lid so masking tape will adhere.  
2. On the **top** of the box, tape the printed template in place and align it with the centre of the lid as shown in the PDF / images.  
3. Mark the following on the box with a non‑permanent marker:  
   - **Main fan/filter opening:** 250 × 195 mm rectangular cutout.  
   - **Fan mounting holes:** 4 × holes at the corners for M4 screws (drill 4 mm).  
4. On the **front side of the lid**, mark two circular openings for the glove ports:  
   - **Glove inserts:** 2 × circles, 96 mm diameter each.  
5. On the **left side of the box**, mark:  
   - **Large insert:** 1 × circle, 72 mm diameter.  
   - **Cable insert:** 1 × hole, 12 mm diameter.

Top of the box with rectangular cutout and four drilled holes for fan/filter assembly

Front of the lid with two circular cutouts for glove inserts

Left side of the box with one large circular cutout and one small hole

> [!WARNING] Check dimensions twice  
> Before cutting, verify all positions and diameters with the corresponding 3D‑printed inserts. The parts should cover a few millimetres of plastic around each cutout for a good seal.

#### Step 1.2 – Cutting and drilling

Cutting the openings in the plastic box

1. Drill a starter hole inside each closed shape (rectangles / circles) using a drill bit sized for your cutting tool (e.g. 6–8 mm).  
2. For the **rectangular top opening**, insert a fine‑tooth jigsaw blade or rotary tool and carefully cut along the marked lines.  
3. For the **circular openings**, use a hole saw, step bit, or carefully cut along the line with a rotary tool.  
4. Drill the **M4 mounting holes** (4 mm diameter) at the marked fan / filter positions.  
5. Deburr all edges with a file or fine sandpaper so the printed parts sit flush.

Deburring and finishing the cutouts

> [!WARNING] Cutting plastic safely  
> - Wear safety glasses and a dust mask.  
> - Clamp the box securely so it cannot move while cutting.  
> - Work slowly to avoid cracking the plastic.

---

### 2. Fan assembly

Printed fan baseplate and brackets with fan

In this step you assemble the fan on its printed baseplate and outer brackets.

#### Step 2.1 – Mount the fan to the baseplate

Attaching the fan to the printed baseplate

1. Place the `Fan_Baseplate` on your workspace with the flat side down.  
2. Orient the 120 mm fan so that it will **blow air into the box** when mounted (the airflow arrow on most fans should point towards the box).  
3. Align the fan’s mounting holes with those in the `Fan_Baseplate`.  
4. Use four suitable screws (e.g. M4 × 12 mm) to fasten the fan to the baseplate.

> [!TIP] Fan orientation  
> If your fan has a label and struts on one side: usually the **strut side** is the air outlet. For this design, the outlet should face **towards the box**.

#### Step 2.2 – Attach outer brackets

Adding outer brackets and connector bracket

Outer brackets detail
Outer brackets from different angle
Assembled fan module with brackets

1. Attach the `Fan_Connector‑Bracket` and `Fan_Outer‑Bracket`s to the `Fan_Baseplate` according to the exploded view in the project files.  
2. Use M4 screws and nuts where provided to secure the brackets.  
3. Double‑check that all parts sit flat and that nothing interferes with the fan blades.

---

### 3. Mounting fan and filter on the box

Box with cutouts ready for mounting fan and filter
Test‑fitting the fan module on the top opening

In this step you clamp the HEPA filter and the fan assembly to the top of the box.

#### Step 3.1 – Position the HEPA filter

Positioning the HEPA filter over the top cutout
Aligning filter edges and mounting holes

1. Place the box so that the top opening faces upwards.  
2. Lay the HEPA filter on the **inside** of the lid or box top so it completely covers the 250 × 195 mm rectangular cutout.  
3. Align the edges so that the filter frame sits evenly and there is enough overlap for a good seal.  
4. The filter should stay in place on its own, sitting on the outer lip.

Placing printed filter holder clamps inside the box
Filter clamped with printed parts

5. Position the `Filter_Holder‑Clamp` parts on the inside, over the filter frame, aligned with the drilled M4 holes.

#### Step 3.2 – Clamp fan and filter together

Inserting long screws through fan, lid and filter clamps
Tightening nuts to clamp filter and fan
View from inside showing filter clamped
Fan and filter fully mounted – outside view
Fan and filter fully mounted – inside view
Fan and filter assembly close‑up

1. Place the assembled fan module on the **outside** of the box, over the rectangular opening.  
2. Align the fan bracket holes with the drilled M4 holes and the `Filter_Holder‑Clamp`s inside the box.  
3. Insert four long M4 screws (e.g. M4 × 65 mm) from the outside through: fan bracket → box lid → filter clamp.  
4. On the inside, place M4 nuts on each screw and tighten them evenly until the filter and fan are clamped firmly and the plastic deforms only slightly.  
5. Verify that the fan blades spin freely and that the filter frame is compressed all around for a good seal.

> [!WARNING] Do not overtighten  
> Excessive torque on the screws may crack the box wall or warp the filter frame. Tighten only until nothing moves when pushed gently.

---

### 4. Box inserts (cable and service ports)

Overview of printed inserts installed in the side wall

This section covers the smaller side ports: a cable feedthrough and a larger service port (65–72 mm insert).

#### Step 4.1 – Cable insert

Cable insert – inside view
Cable insert – parts and assembly
Cable insert – outside view with nut
Cable insert – cover installed

1. From the **inside** of the box, insert the `Cable‑Insert_Inner` through the 12 mm cable hole.  
2. From the **outside**, thread the `Cable‑Insert_Nut` onto the protruding part and hand‑tighten until the box wall is clamped firmly between the two parts.  
3. When no cables are routed, close the port with the `Cable‑Insert_Cover`.  
4. To route a cable, remove the cover, feed the cable through, and reseal as well as possible with tape or a custom drilled cover.

#### Step 4.2 – Large service insert (65–72 mm)

Large service insert – inner part
Large service insert – outer open cover
Large service insert – outer closed cover
Large service insert fully assembled

1. From the **inside** of the box, place the `Large‑Insert_Inner` into the 72 mm side opening.  
2. From the **outside**, align the appropriate outer cover (`Large‑Insert_Outer‑Cover‑Open` or `Large‑Insert_Outer‑Cover‑Closed`) and fasten it to the inner part according to the design (screws or bayonet lock).  
3. Use the **closed cover** when maximum sealing is required.  
4. Use the **open cover** variant to pass larger objects in or out of the box while keeping the opening controlled and easy to re‑seal.

---

### 5. Gloves

Glove ports and gloves mounted in the lid

#### Step 5.1 – Choosing gloves

Select gloves that:  
- Are **long enough** to reach all areas in the box.  
- Have a **cuff diameter** compatible with the `Glove‑Insert_Inner` and `Glove‑Insert_Outer‑Ring`.  
- Are made from a material resistant to any solvents or chemicals you expect to use (e.g. nitrile or thicker dishwashing gloves).

> [!TIP] Test fit one glove first  
> Before assembling both ports, test the fit with one glove and adjust how far you roll the cuff to achieve a good seal and comfortable reach.

#### Step 5.2 – Mounting the glove screw‑on inserts

Mounting glove on inner insert
Clamping glove with outer ring
Glove insert fully mounted in lid

1. Turn the lid so the **inside** faces up. Insert the `Glove‑Insert_Inner` into one of the 96 mm circular openings from the inside.  
2. Slide the glove cuff over the inner insert so that ~3–5 cm of the glove overlaps the flange.  
3. Place the `Glove‑Insert_Outer‑Ring` over the glove from the outside of the lid and push it onto the inner insert, clamping the glove material in between.  
4. Ensure the glove is clamped evenly all around and cannot be pulled out by gentle force.  
5. Repeat the procedure for the second glove port.

> [!WARNING] Do not overstretch the glove cuff  
> Overstretching can lead to tears. If the glove material feels too tight, choose a larger insert size or a different glove model.

---

### 6. Wiring and first test

#### Step 6.1 – Connect fans to the power supply

> [!DANGER] Mains safety  
> If you need to modify a mains‑powered supply, only do so if you are qualified to work with mains voltages. Otherwise use an off‑the‑shelf, enclosed 12 V supply and keep all mains wiring outside the glove box.

1. Connect both 120 mm fans **in parallel** to the 12 V DC output of your power supply:  
   - All positive (red) wires together to **+12 V**.  
   - All negative (black) wires together to **GND**.  
2. If you want adjustable airflow, you can add a simple fan controller or a PWM speed control module between the supply and the fans.  
3. Route the fan power cable along the box by taping it or at least make sure it won't accidentally get into the fan blades.

#### Step 6.2 – Check overpressure and leaks

1. Close the lid and ensure all ports (large insert, cable insert, glove rings) are fully assembled.  
2. Turn on the fans. After a few seconds, the lid may bulge slightly as pressure builds.  
3. Hold a thin strip of tissue paper or incense stick **near** (not inside) suspected leak points around the lid and inserts: the strip should blow **outwards**, not be sucked in.  
4. If you detect inward leaks, check and re‑seat the inserts or consider adding sealing tape.

Your overpressure glove box is now ready to use for clean assembly of the Raman optical components.

---

## Continue reading

- [Basic Raman Optical Assembly](Basic%20Raman%20Optical%20Assembly.md)  
- [Linear Translation Stage](Linear%20Translation%20Stage.md)

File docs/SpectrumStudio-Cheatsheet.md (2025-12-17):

# Software Quick Guide

Acquisition Software Spectrum Studio showing a raman spectrum of toluene with background subtracted at 3000ms integration time and 5 averages

SpectrumStudio is the original **control and acquisition software** for the BTC110 / B&W Tek OEM spectrometer used in DIYraman.  

[Click to Download - SpectrumStudio](https://drive.google.com/file/d/1ooKja8GXg5gMX-swFjbmAXFP61ucyWT_/view?usp=sharing)

**It is used to:**
- Set **integration time** and **averaging**
- Apply **background subtraction**
- Use a **wavelength calibration**
- Save spectra as **CSV** for analysis and open-hardware documentation

> [!NOTE] Adapted from software handbook
> The following reference is summarized and adapted from the handbook built in to the software. More information can be found in SpectrumStudio under *Help* → *Contents* or by pressing *CTRL+F1*.

---

## Minimal workflow

1. **Detect the spectrometer**  
   Click Detect spectrometers → creates a tab for each device.

2. **Set exposure & noise level**  
   - **Integration time:** type value in the *Integration Time* box (e.g. `50 ms`, `250 ms`, `2500 ms`).  
   - **Averages:** set a small number (e.g. `3–15`) in *Averages*.

3. **Start measuring**  
   - Live view: Scan continuously (*Scan Continuously*)  
   - Single snapshot: Scan once (*Scan Once*)

4. **Set a dark background (recommended)**  
   - Block light (objective capped / finger on input).  
   - Take a scan, then click Set background (*Use current scan as background*).  
   → All future spectra are **background-subtracted**.

5. **Scan again**  
   - Take another scan.
   → Now the output spectrum is background-subtracted.
   - When adjusting the *integration time*, record a new background to subtract.

6. **Save spectrum data**  
   - Click Save or **File → Save As…**  
   - Store the CSV together with: sample ID, integration time, averages, background on/off, calibration version.

5. **(Optional, as-needed) Adjust wavelength calibration**  
   - Record a lamp (CFL/neon).  
   - Click Calibration and tweak coefficients so known lines match their wavelengths.

---

## Essential features at a glance

**Text fields:**
- *Integration Time* – exposure in ms (typ. 50–65000 ms).  
- *Averages* – number of scans the PC averages before showing one spectrum.

| Icon | Control | What it does (in one sentence) |
| --- | --- | --- |
| Detect | **Detect Spectrometers** | Scans all COM ports and opens one tab per detected spectrometer. |
| Scan continuously | **Scan Continuously** | Repeats scans with current settings for a live spectrum view. |
| Scan once | **Scan Once** | Acquires exactly one spectrum - or number of *Averages* - defined. |
| Stop | **Stop** | Finishes the current scan and then stops continuous acquisition. |
| Set background | **Set Background**<br>/<br>**Clear Background** | Stores current spectrum as dark/background and subtracts it from future scans.<br>/<br>Disables background subtraction (background = zero). |
| Log on / Log off | **Log Data** (On/Off) | When enabled, every finished spectrum is written to disk (see Options → Data Logging). |
| Calibration | **Wavelength Calibration** | View or edit pixel→wavelength polynomial coefficients. |

---

## Graph interaction & cursors

| Icon | Action | Use it for |
| --- | --- | --- |
| Pointer | **Pointer / Default**  | Move **cursors** and interact normally with the graph. |
| Pan | **Pan** | Drag the view around (hold **Ctrl** over the graph for temporary pan). |
| ZoomXY | **Zoom X+Y** | Draw a rectangle to zoom into a region (hold **Shift** for temporary zoom). |
| ZoomX | **Zoom X** | Zoom only along wavelength/pixel. |
| ZoomY | **Zoom Y** | Zoom only along intensity. |
| ZoomOut | **Zoom Out** | Step back out of previous zoom levels (right-click on the graph). |
| Cursors | **Cursors / Line ID**  | Show a vertical cursor for precise wavelength/line lookup and a horizontal cursor for intensity comparison. |
| YAxis | **Linear / Log scale** | Switch Y-axis between linear and logarithmic intensity. |

---

[Spectrometer-Setup](Spectrometer-Setup.md)

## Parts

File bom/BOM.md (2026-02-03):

# Parts list (BOM)

---

## [Core-Assembly](../docs/Core-Assembly.md)

### Sourced parts

| Qty  | Name | Model / Spec | Supplier | Notes | Used in | Cost (total) |
| ---- | --- | --- | --- | --- | --- | --- |
| 1-2x | Quartz Cuvette | Any | eBay Marketplace | 1x is sufficient, but two cuvettes facilitate calibration (sample cuvette & fluorescent cuvette), matching the dimensions of `Kuvettecase_Bottom` and `Kuvettecase_Top`. | [Sample Assembly](../docs/Core-Assembly.md#Sample%20Assembly) | 20€ |
| 1x | Microscope objective | Any, Leitz PL Fluotar 20x/0.45 D EPI, oo/0 | eBay Marketplace | Any, 20x, inf.- corrected, WD > Cuvette-Thickness (alternative to printed part: [CP42/M](https://www.thorlabs.de/thorproduct.cfm?partnumber=CP42/M)) | [Sample Assembly](../docs/Core-Assembly.md#Sample%20Assembly) | 80€ |
| 4x | Guide Rod ⌀ 6 mm, 100 mm | Any, [ER Assembly Rods for 30 mm Cage Systems](https://www.thorlabs.de/newgrouppage9.cfm?objectgroup_ID=4125) i.e. [ER4](https://www.thorlabs.de/thorproduct.cfm?partnumber=ER4) (4" ~ 100 mm) | Thorlabs / eBay Marketplace / various | Ideally for optical applications (tight tolerances) | [Sample Assembly](../docs/Core-Assembly.md#Sample%20Assembly), [Focusing Assembly](../docs/Core-Assembly.md#Focusing%20Assembly) | - |
| 1x | Laser 532nm | Any, 532 nm DPSS, 30mW - 70mW, (⌀ 18 mm) | Aliexpress | Cylindrical laser module, 18 mm body. | [Laser Assembly](../docs/Core-Assembly.md#Laser%20Assembly) | 25€ |
| 2x | Kinematic Mount | Thorlabs KM100 | Thorlabs | Kinematic mirror mount. | [Laser Assembly](../docs/Core-Assembly.md#Laser%20Assembly), [Dichroic Assembly](../docs/Core-Assembly.md#Dichroic%20Assembly) | 90€ |
| 1x | Longpass filter (550 nm) | Thorlabs FELH0550 | Thorlabs | | [Focusing Assembly](../docs/Core-Assembly.md#Focusing%20Assembly) | 170€ |
| 1x | Focusing lens | [Thorlabs AC127-019-A](https://www.thorlabs.de/thorproduct.cfm?partnumber=AC127-019-A) - f = 19 mm, Ø1/2" Achromatic Doublet | Thorlabs | (mounted in [CP32/M](https://www.thorlabs.com/thorproduct.cfm?partnumber=CP32/M)) | [Focusing Assembly](../docs/Core-Assembly.md#Focusing%20Assembly) | 60€ |
| 1x | Dichroic mirror (550 nm) | Thorlabs DMLP550 | Thorlabs | | [Dichroic Assembly](../docs/Core-Assembly.md#Dichroic%20Assembly) | 230€ |
| 8x | M3 screw + nut | Any | - | | [Sample Assembly](../docs/Core-Assembly.md#Sample%20Assembly), [Focusing Assembly](../docs/Core-Assembly.md#Focusing%20Assembly) | - |
| 4x | M4 heat-set insert | Any | - | | [Laser Assembly](../docs/Core-Assembly.md#Laser%20Assembly), [Dichroic Assembly](../docs/Core-Assembly.md#Dichroic%20Assembly) | - |
| 7x | M3 heat-set insert | Any | - | | [Laser Assembly](../docs/Core-Assembly.md#Laser%20Assembly), [Focusing Assembly](../docs/Core-Assembly.md#Focusing%20Assembly) | - |

### Printed parts

| Qty | Part name (.stl) | Used in |
| --- | --- | --- |
| 4x  | `Defaultholder` | [Sample Assembly](../docs/Core-Assembly.md#Sample%20Assembly), [Focusing Assembly](../docs/Core-Assembly.md#Focusing%20Assembly) |
| 4x  | `Rodholder` | [Sample Assembly](../docs/Core-Assembly.md#Sample%20Assembly), [Focusing Assembly](../docs/Core-Assembly.md#Focusing%20Assembly) |
| 1x  | `Sample-Stage` | [Sample Assembly](../docs/Core-Assembly.md#Sample%20Assembly) |
| 1x  | `Kuvettecase_Top` | [Sample Assembly](../docs/Core-Assembly.md#Sample%20Assembly) |
| 1x  | `Kuvettecase_Bottom` | [Sample Assembly](../docs/Core-Assembly.md#Sample%20Assembly) |
| 1x  | `Objective-Mount_Insert` | [Sample Assembly](../docs/Core-Assembly.md#Sample%20Assembly) |
| 1x  | `Laser_KM100-Insert` | [Laser Assembly](../docs/Core-Assembly.md#Laser%20Assembly) |
| 1x  | `Laser_KM100-Mount` | [Laser Assembly](../docs/Core-Assembly.md#Laser%20Assembly) |
| 1x  | `SMA905_Insert` | [Focusing Assembly](../docs/Core-Assembly.md#Focusing%20Assembly) |
| 1x  | `Dichroic_KM100-Mount` | [Dichroic Assembly](../docs/Core-Assembly.md#Dichroic%20Assembly) |
| 1x  | `Baseplate_Small` | [Baseplate Mounting](../docs/Core-Assembly.md#Baseplate%20Mounting) |

## Various

| Qty  | Name | Model / Spec | Supplier | Notes | Used in | Cost (total) |
| ---- | --- | --- | --- | --- | --- | --- |
| 1x | Laser safety glasses  | PROTECT-Laserschutz Terminator, Filter 0277 | [PROTECT-Laserschutz](https://protect-laserschutz.de/de/shop/~p1924) | Any laser safety glasses for 532nm (DONT BUY CHEAP CHINESE KNOCK-OFFS HERE!) | EVERYWHERE | 130€ |
| 1x | 3D-printing filament  | PETG-CF (Black) | - | - | EVERYWHERE | 25€ |
| 1x | Fluorescent dye | Rhodamine B (*CAS: 81-88-9*), 5g | eBay | Any strong fluorescent material with excitation at around the laser's wavelength (532 nm) | [Align-with-Fluorescence](../docs/Align-with-Fluorescence.md) | 15€ |
| 1x | Bandpass filter 532nm | Edmund Optics #65640 | Edmund Optics | OPTIONAL FOR NOW (use for cheap laser) | Final Raman Assembly | 95€ |
| 2-4x | (Optional) Cage Plate | 30 mm cage plate, https://www.thorlabs.de/newgrouppage9.cfm?objectgroup_id=2273 | Any, Thorlabs, Edmund Optics | Offers a thread, unlike the printed *Defaultholder* | | |

## [Spectrometer-Setup](../docs/Spectrometer-Setup.md)

### Sourced parts

| Qty | Name | Model / Spec | Supplier | Notes | Used in | Cost (total) |
| --- | --- | --- | --- | --- | --- | --- |
| 1x  | Spectrometer unit | B&W Tek BTC100-2S | [eBay](https://www.ebay.com/itm/143989529085) | Or any other spectrometer - ideally with SMA905 input, if you use fiber. | [Spectrometer-Setup](../docs/Spectrometer-Setup.md) | 200€ |
| 1x  | Fiber optic cable, 200 μm | Any, SMA905-SMA905 1m VIS-IR 200um | Any, Aliexpress | - | [Spectrometer-Setup](../docs/Spectrometer-Setup.md) | 50€ |
| 1x  | Data cable | RS-232 to USB | Amazon | Choose a chipset compatible with your OS (many FTDI / Prolific chips work reliably). | [Spectrometer-Setup](../docs/Spectrometer-Setup.md) | 15€ |
| 1x  | Power supply | 5V, ~3A, DC barrel jack | Amazon | | [Spectrometer-Setup](../docs/Spectrometer-Setup.md) | 15€ |
| 1x  | Calibration lamp | Dedicated calibration / CFL / mercury-vapor lamp | Any, eBay Marketplace | Needs several sharp lines near ~550 nm for wavelength calibration. | [Spectrometer-Setup](../docs/Spectrometer-Setup.md) | 25€ |

### Printed parts

| Qty | Part name (.stl) | Used in |
| --- | --- | --- |
| 1x  | `Spectrometer-Case_Bottom` | [Spectrometer-Setup](../docs/Spectrometer-Setup.md) |
| 1x  | `Spectrometer-Case_Top` | [Spectrometer-Setup](../docs/Spectrometer-Setup.md) |
| 1x  | `Spectrometer_Screw-Cover` | [Spectrometer-Setup](../docs/Spectrometer-Setup.md) |

## [Dustproof-Workspace](../docs/Dustproof-Workspace.md)

### Sourced parts

| Qty | Name | Model / Spec | Supplier | Notes | Used in | Cost (total) |
| --- | --- | --- | --- | --- | --- | --- |
| 1x | Storage box | IKEA SAMLA, transparent, <br>57×39×42 cm | [IKEA](https://www.ikea.com/de/en/p/samla-box-with-lid-transparent-s99440774/) | Any similar box works, separate lid that forms tight seal is ideal. | [Dustproof-Workspace](../docs/Dustproof-Workspace.md) | 12€ |
| 1x | HEPA filter | IKEA UPPATVIND | [IKEA](https://www.ikea.com/de/en/p/uppatvind-filter-for-particle-removal-90551498/) | Any HEPA / fine dust filter of similar size works. Higher filtration = more pressure drop. | [Dustproof-Workspace](../docs/Dustproof-Workspace.md) | 5€ |
| 2x | PC fan | Any, 120 mm PC fan | - | 12V DC fans. Check current draw and airflow rating. | [Dustproof-Workspace](../docs/Dustproof-Workspace.md) | 10€ |
| 2x | Gloves | Any, long‑sleeved chemical or dishwashing gloves | - | Choose gloves long enough to reach all areas inside the box. | [Dustproof-Workspace](../docs/Dustproof-Workspace.md) | 2€ |
| 14x | M4 screw + nut | Hex socket head cap screw | Any | Mixture of lengths below. | [Dustproof-Workspace](../docs/Dustproof-Workspace.md) | - |
| 4x<br>4x<br>2x<br>4x | | M4 × 12 mm<br>M4 × 16 mm<br>M4 × 20 mm<br>M4 × 65 mm | | | | |

### Printed parts

| Qty | Part name (.stl) | Used in |
| --- | --- | --- |
| 1x  | `Fan_Connector‑Bracket` | [Dustproof-Workspace](../docs/Dustproof-Workspace.md) Fan / filter assembly |
| 1x  | `Fan_Baseplate` | [Dustproof-Workspace](../docs/Dustproof-Workspace.md) Fan / filter assembly |
| 2x  | `Filter_Holder‑Clamp` | [Dustproof-Workspace](../docs/Dustproof-Workspace.md) Fan / filter assembly |
| 4x  | `Fan_Outer‑Bracket` | [Dustproof-Workspace](../docs/Dustproof-Workspace.md) Fan / filter assembly |
| 2x  | `Glove‑Insert_Inner` | [Dustproof-Workspace](../docs/Dustproof-Workspace.md) Glove ports |
| 2x  | `Glove‑Insert_Outer‑Ring` | [Dustproof-Workspace](../docs/Dustproof-Workspace.md) Glove ports |
| 1x  | `Large‑Insert_Inner` | [Dustproof-Workspace](../docs/Dustproof-Workspace.md) Large service port |
| 1x  | `Large‑Insert_Threaded‑Cover` | [Dustproof-Workspace](../docs/Dustproof-Workspace.md) Large service port |
| 1x  | `Large‑Insert_Outer‑Cover‑Open` | [Dustproof-Workspace](../docs/Dustproof-Workspace.md) Large service port |
| 1x  | `Large‑Insert_Outer‑Cover‑Closed` | [Dustproof-Workspace](../docs/Dustproof-Workspace.md) Large service port |
| 1x  | `Cable‑Insert_Inner` | [Dustproof-Workspace](../docs/Dustproof-Workspace.md) Cable / feedthrough port |
| 1x  | `Cable‑Insert_Nut` | [Dustproof-Workspace](../docs/Dustproof-Workspace.md) Cable / feedthrough port |
| 1x  | `Cable‑Insert_Cover` | [Dustproof-Workspace](../docs/Dustproof-Workspace.md) Cable / feedthrough port |

## [DIY-Linear-Stage](../docs/DIY-Linear-Stage.md)

### Sourced parts

| Qty | Name | Model / Spec | Supplier | Notes | Used in | Cost (total) |
| --- | --- | --- | --- | --- | --- | --- |
| 1x  | Micrometer screw | ~10-15 mm travel | Aliexpress | With mounting nut/collar | [DIY-Linear-Stage](../docs/DIY-Linear-Stage.md) | 10€ |
| 2x  | Guide Rod ⌀ 6 mm, 55 mm | Any, [ER Assembly Rods for 30 mm Cage Systems](https://www.thorlabs.de/newgrouppage9.cfm?objectgroup_ID=4125) | Thorlabs / eBay Marketplace / various | Ideally for optical applications (tight tolerances) | [DIY-Linear-Stage](../docs/DIY-Linear-Stage.md) | - |
| 2x  | Compression spring | ⌀ ≥ 6 mm | Any | Stiffness chosen for light pre-load | [DIY-Linear-Stage](../docs/DIY-Linear-Stage.md) | - |
| 4x  | M3.5 screw + washer + nut | ~12 mm length | Any | | [DIY-Linear-Stage](../docs/DIY-Linear-Stage.md) | - |

### Printed parts

| Qty | Part name (.stl) | Used in |
| --- | --- | --- |
| 1x  | `LinearStage_Base` | [DIY-Linear-Stage](../docs/DIY-Linear-Stage.md) |
| 1x  | `LinearStage_Stage` | [DIY-Linear-Stage](../docs/DIY-Linear-Stage.md) |
| 1x  | `LinearStage_Frontplate` | [DIY-Linear-Stage](../docs/DIY-Linear-Stage.md) |
| 1x  | `LinearStage_L-Bracket`  | [DIY-Linear-Stage](../docs/DIY-Linear-Stage.md) |

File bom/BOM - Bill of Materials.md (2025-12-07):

# Parts and Materials

---

## [Basic Raman Optical Assembly](Basic%20Raman%20Optical%20Assembly.md)

### Sourced parts

| Qty  | Name | Model / Spec | Supplier | Notes | Used in | Cost (total) |
| ---- | --- | --- | --- | --- | --- | --- |
| 1-2x | Quartz Cuvette | Any | eBay Marketplace | 1x is sufficient, but two cuvettes facilitate calibration (sample cuvette & fluorescent cuvette), matching the dimensions of `Kuvettecase_Bottom` and `Kuvettecase_Top`. | [Sample Assembly](#Sample%20Assembly) | 20€ |
| 1x | Microscope objective | Any, Leitz PL Fluotar 20x/0.45 D EPI, oo/0 | eBay Marketplace | Any, 20x, inf.- corrected, WD > Cuvette-Thickness (alternative to printed part: [CP42/M](https://www.thorlabs.de/thorproduct.cfm?partnumber=CP42/M)) | [Sample Assembly](#Sample%20Assembly) | 80€ |
| 4x | Guide Rod ⌀ 6 mm, 100 mm | Any, [ER Assembly Rods for 30 mm Cage Systems](https://www.thorlabs.de/newgrouppage9.cfm?objectgroup_ID=4125) i.e. [ER4](https://www.thorlabs.de/thorproduct.cfm?partnumber=ER4) (4" ~ 100 mm) | Thorlabs / eBay Marketplace / various | Ideally for optical applications (tight tolerances) | [Sample Assembly](#Sample%20Assembly), [Focusing Assembly](#Focusing%20Assembly) | - |
| 1x | Laser 532nm | Any, 532 nm DPSS, 30mW - 70mW, (⌀ 18 mm) | Aliexpress | Cylindrical laser module, 18 mm body. | [Laser Assembly](#Laser%20Assembly) | 25€ |
| 2x | Kinematic Mount | Thorlabs KM100 | Thorlabs | Kinematic mirror mount. | [Laser Assembly](#Laser%20Assembly), [Dichroic Assembly](#Dichroic%20Assembly) | 90€ |
| 1x | Longpass filter (550 nm) | Thorlabs FELH0550 | Thorlabs | | [Focusing Assembly](#Focusing%20Assembly) | 170€ |
| 1x | Focusing lens | [Thorlabs AC127-019-A](https://www.thorlabs.de/thorproduct.cfm?partnumber=AC127-019-A) - f = 19 mm, Ø1/2" Achromatic Doublet | Thorlabs | (mounted in [CP32/M](https://www.thorlabs.com/thorproduct.cfm?partnumber=CP32/M)) | [Focusing Assembly](#Focusing%20Assembly) | 60€ |
| 1x | Dichroic mirror (550 nm) | Thorlabs DMLP550 | Thorlabs | | [Dichroic Assembly](#Dichroic%20Assembly) | 230€ |
| 8x | M3 screw + nut | Any | - | | [Sample Assembly](#Sample%20Assembly), [Focusing Assembly](#Focusing%20Assembly) | - |
| 4x | M4 heat-set insert | Any | - | | [Laser Assembly](#Laser%20Assembly), [Dichroic Assembly](#Dichroic%20Assembly) | - |
| 7x | M3 heat-set insert | Any | - | | [Laser Assembly](#Laser%20Assembly), [Focusing Assembly](#Focusing%20Assembly) | - |

### Printed parts

| Qty | Part name (.stl) | Used in |
| --- | --- | --- |
| 4x  | `Defaultholder` | [Sample Assembly](#Sample%20Assembly), [Focusing Assembly](#Focusing%20Assembly) |
| 4x  | `Rodholder` | [Sample Assembly](#Sample%20Assembly), [Focusing Assembly](#Focusing%20Assembly) |
| 1x  | `Sample-Stage` | [Sample Assembly](#Sample%20Assembly) |
| 1x  | `Kuvettecase_Top` | [Sample Assembly](#Sample%20Assembly) |
| 1x  | `Kuvettecase_Bottom` | [Sample Assembly](#Sample%20Assembly) |
| 1x  | `Objective-Mount_Insert` | [Sample Assembly](#Sample%20Assembly) |
| 1x  | `Laser_KM100-Insert` | [Laser Assembly](#Laser%20Assembly) |
| 1x  | `Laser_KM100-Mount` | [Laser Assembly](#Laser%20Assembly) |
| 1x  | `SMA905_Insert` | [Focusing Assembly](#Focusing%20Assembly) |
| 1x  | `Dichroic_KM100-Mount` | [Dichroic Assembly](#Dichroic%20Assembly) |
| 1x  | `Baseplate_Small` | [Baseplate Mounting](#Baseplate%20Mounting) |

## Various

| Qty  | Name | Model / Spec | Supplier | Notes | Used in | Cost (total) |
| ---- | --- | --- | --- | --- | --- | --- |
| 1x | Laser safety glasses  | PROTECT-Laserschutz Terminator, Filter 0277 | [PROTECT-Laserschutz](https://protect-laserschutz.de/de/shop/~p1924) | Any laser safety glasses for 532nm (DONT BUY CHEAP CHINESE KNOCK-OFFS HERE!) | EVERYWHERE | 130€ |
| 1x | 3D-printing filament  | PETG-CF (Black) | - | - | EVERYWHERE | 25€ |
| 1x | Fluorescent dye | Rhodamine B (*CAS: 81-88-9*), 5g | eBay | Any strong fluorescent material with excitation at around the laser's wavelength (532 nm) | [Rhodamine B](Rhodamine%20B.md) | 15€ |
| 1x | Bandpass filter 532nm | Edmund Optics #65640 | Edmund Optics | OPTIONAL FOR NOW (use for cheap laser) | Final Raman Assembly | 95€ |
| 2-4x | (Optional) Cage Plate | 30 mm cage plate, https://www.thorlabs.de/newgrouppage9.cfm?objectgroup_id=2273 | Any, Thorlabs, Edmund Optics | Offers a thread, unlike the printed *Defaultholder* | | |

## [Spectrometer Unit](Spectrometer%20Unit.md)

### Sourced parts

| Qty | Name | Model / Spec | Supplier | Notes | Used in | Cost (total) |
| --- | --- | --- | --- | --- | --- | --- |
| 1x  | Spectrometer unit | B&W Tek BTC100-2S | [eBay](https://www.ebay.com/itm/143989529085) | Or any other spectrometer - ideally with SMA905 input, if you use fiber. | [Spectrometer Unit](Spectrometer%20Unit.md) | 200€ |
| 1x  | Fiber optic cable, 200 μm | Any, SMA905-SMA905 1m VIS-IR 200um | Any, Aliexpress | - | [Spectrometer Unit](Spectrometer%20Unit.md) | 50€ |
| 1x  | Data cable | RS-232 to USB | Amazon | Choose a chipset compatible with your OS (many FTDI / Prolific chips work reliably). | [Spectrometer Unit](Spectrometer%20Unit.md) | 15€ |
| 1x  | Power supply | 5V, ~3A, DC barrel jack | Amazon | | [Spectrometer Unit](Spectrometer%20Unit.md) | 15€ |
| 1x  | Calibration lamp | Dedicated calibration / CFL / mercury-vapor lamp | Any, eBay Marketplace | Needs several sharp lines near ~550 nm for wavelength calibration. | [Spectrometer Unit](Spectrometer%20Unit.md) | 25€ |

### Printed parts

| Qty | Part name (.stl) | Used in |
| --- | --- | --- |
| 1x  | `Spectrometer-Case_Bottom` | [Spectrometer Unit](Spectrometer%20Unit.md) |
| 1x  | `Spectrometer-Case_Top` | [Spectrometer Unit](Spectrometer%20Unit.md) |
| 1x  | `Spectrometer_Screw-Cover` | [Spectrometer Unit](Spectrometer%20Unit.md) |

## [Overpressure Glove Box](Overpressure%20Glove%20Box.md)

### Sourced parts

| Qty | Name | Model / Spec | Supplier | Notes | Used in | Cost (total) |
| --- | --- | --- | --- | --- | --- | --- |
| 1x | Storage box | IKEA SAMLA, transparent, <br>57×39×42 cm | [IKEA](https://www.ikea.com/de/en/p/samla-box-with-lid-transparent-s99440774/) | Any similar box works, separate lid that forms tight seal is ideal. | [Overpressure Glove Box](Overpressure%20Glove%20Box.md) | 12€ |
| 1x | HEPA filter | IKEA UPPATVIND | [IKEA](https://www.ikea.com/de/en/p/uppatvind-filter-for-particle-removal-90551498/) | Any HEPA / fine dust filter of similar size works. Higher filtration = more pressure drop. | [Overpressure Glove Box](Overpressure%20Glove%20Box.md) | 5€ |
| 2x | PC fan | Any, 120 mm PC fan | - | 12V DC fans. Check current draw and airflow rating. | [Overpressure Glove Box](Overpressure%20Glove%20Box.md) | 10€ |
| 2x | Gloves | Any, long‑sleeved chemical or dishwashing gloves | - | Choose gloves long enough to reach all areas inside the box. | [Overpressure Glove Box](Overpressure%20Glove%20Box.md) | 2€ |
| 14x | M4 screw + nut | Hex socket head cap screw | Any | Mixture of lengths below. | [Overpressure Glove Box](Overpressure%20Glove%20Box.md) | - |
| 4x<br>4x<br>2x<br>4x | | M4 × 12 mm<br>M4 × 16 mm<br>M4 × 20 mm<br>M4 × 65 mm | | | | |

### Printed parts

| Qty | Part name (.stl) | Used in |
| --- | --- | --- |
| 1x  | `Fan_Connector‑Bracket` | [Overpressure Glove Box](Overpressure%20Glove%20Box.md) Fan / filter assembly |
| 1x  | `Fan_Baseplate` | [Overpressure Glove Box](Overpressure%20Glove%20Box.md) Fan / filter assembly |
| 2x  | `Filter_Holder‑Clamp` | [Overpressure Glove Box](Overpressure%20Glove%20Box.md) Fan / filter assembly |
| 4x  | `Fan_Outer‑Bracket` | [Overpressure Glove Box](Overpressure%20Glove%20Box.md) Fan / filter assembly |
| 2x  | `Glove‑Insert_Inner` | [Overpressure Glove Box](Overpressure%20Glove%20Box.md) Glove ports |
| 2x  | `Glove‑Insert_Outer‑Ring` | [Overpressure Glove Box](Overpressure%20Glove%20Box.md) Glove ports |
| 1x  | `Large‑Insert_Inner` | [Overpressure Glove Box](Overpressure%20Glove%20Box.md) Large service port |
| 1x  | `Large‑Insert_Threaded‑Cover` | [Overpressure Glove Box](Overpressure%20Glove%20Box.md) Large service port |
| 1x  | `Large‑Insert_Outer‑Cover‑Open` | [Overpressure Glove Box](Overpressure%20Glove%20Box.md) Large service port |
| 1x  | `Large‑Insert_Outer‑Cover‑Closed` | [Overpressure Glove Box](Overpressure%20Glove%20Box.md) Large service port |
| 1x  | `Cable‑Insert_Inner` | [Overpressure Glove Box](Overpressure%20Glove%20Box.md) Cable / feedthrough port |
| 1x  | `Cable‑Insert_Nut` | [Overpressure Glove Box](Overpressure%20Glove%20Box.md) Cable / feedthrough port |
| 1x  | `Cable‑Insert_Cover` | [Overpressure Glove Box](Overpressure%20Glove%20Box.md) Cable / feedthrough port |

## [Linear Translation Stage](Linear%20Translation%20Stage.md)

### Sourced parts

| Qty | Name | Model / Spec | Supplier | Notes | Used in | Cost (total) |
| --- | --- | --- | --- | --- | --- | --- |
| 1x  | Micrometer screw | ~10-15 mm travel | Aliexpress | With mounting nut/collar | [Linear Translation Stage](Linear%20Translation%20Stage.md) | 10€ |
| 2x  | Guide Rod ⌀ 6 mm, 55 mm | Any, [ER Assembly Rods for 30 mm Cage Systems](https://www.thorlabs.de/newgrouppage9.cfm?objectgroup_ID=4125) | Thorlabs / eBay Marketplace / various | Ideally for optical applications (tight tolerances) | [Linear Translation Stage](Linear%20Translation%20Stage.md) | - |
| 2x  | Compression spring | ⌀ ≥ 6 mm | Any | Stiffness chosen for light pre-load | [Linear Translation Stage](Linear%20Translation%20Stage.md) | - |
| 4x  | M3.5 screw + washer + nut | ~12 mm length | Any | | [Linear Translation Stage](Linear%20Translation%20Stage.md) | - |

### Printed parts

| Qty | Part name (.stl) | Used in |
| --- | --- | --- |
| 1x  | `LinearStage_Base` | [Linear Translation Stage](Linear%20Translation%20Stage.md) |
| 1x  | `LinearStage_Stage` | [Linear Translation Stage](Linear%20Translation%20Stage.md) |
| 1x  | `LinearStage_Frontplate` | [Linear Translation Stage](Linear%20Translation%20Stage.md) |
| 1x  | `LinearStage_L-Bracket`  | [Linear Translation Stage](Linear%20Translation%20Stage.md) |

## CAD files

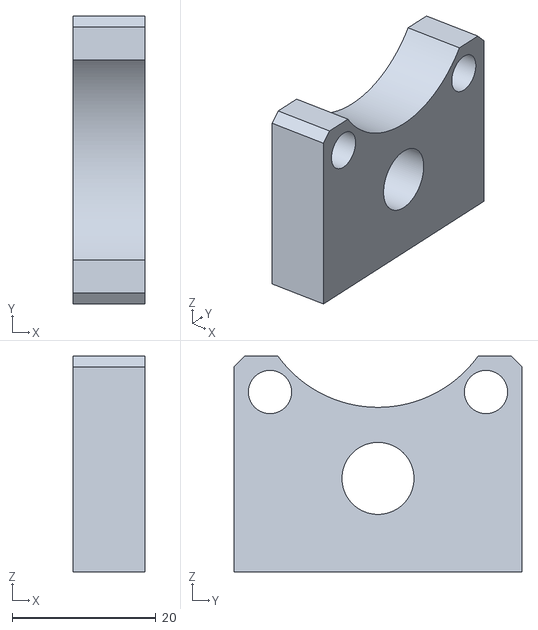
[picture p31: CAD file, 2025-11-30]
parts/basic-assembly/Rodholder.stl
10.0 x 40.0 x 30.0

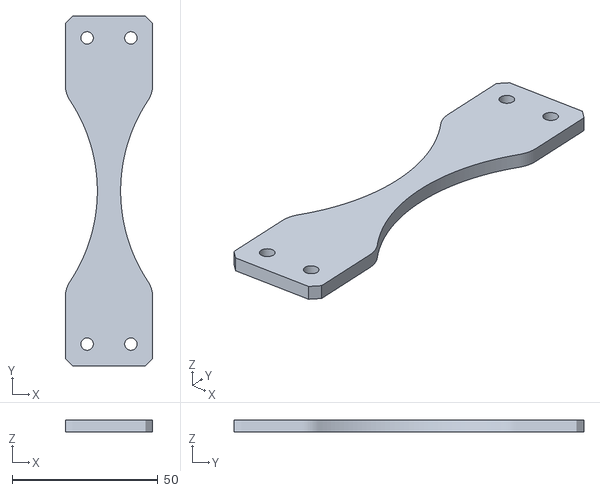
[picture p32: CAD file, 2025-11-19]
parts/glovebox/Fan_Connector-Bracket.stl
30.0 x 120.0 x 4.00

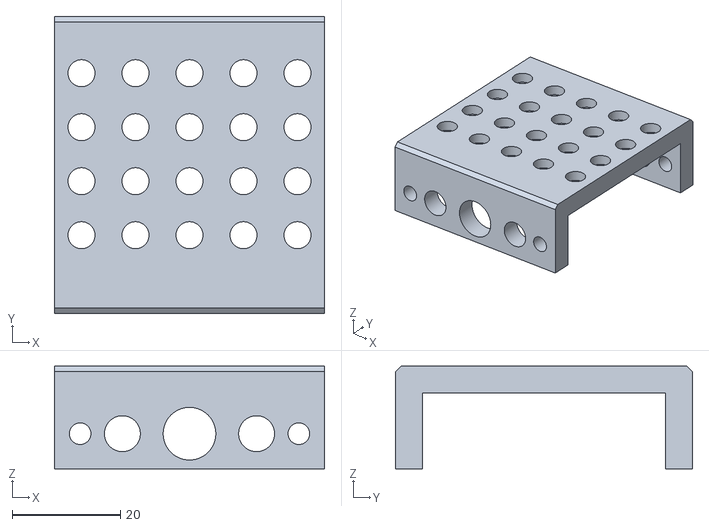
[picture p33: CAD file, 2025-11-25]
parts/translation-stage/LinearStage_Base.stl
50.0 x 55.0 x 19.0

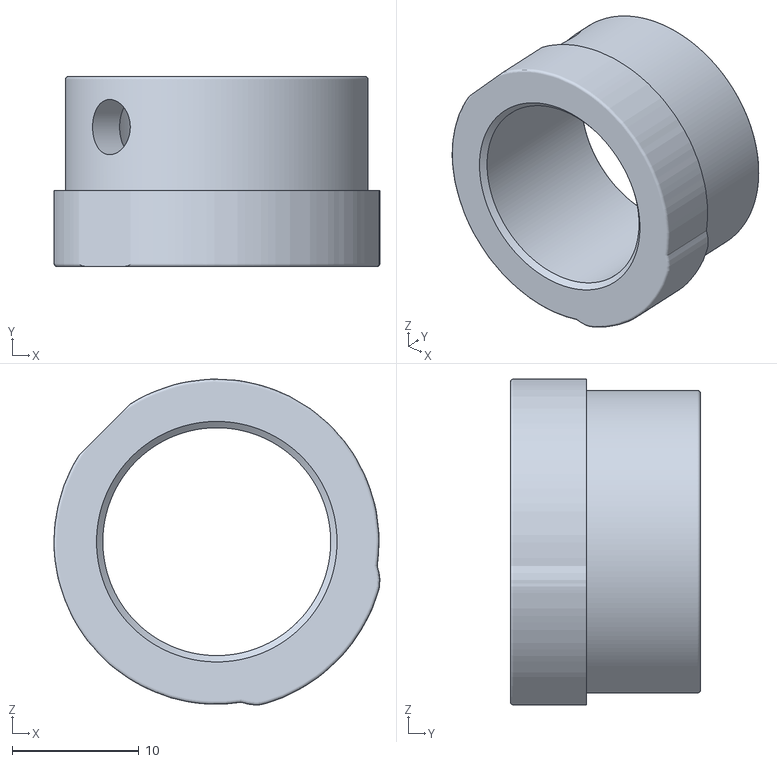
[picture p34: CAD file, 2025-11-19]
parts/basic-assembly/Laser_KM100-Insert.stl
25.7 x 15.0 x 25.7

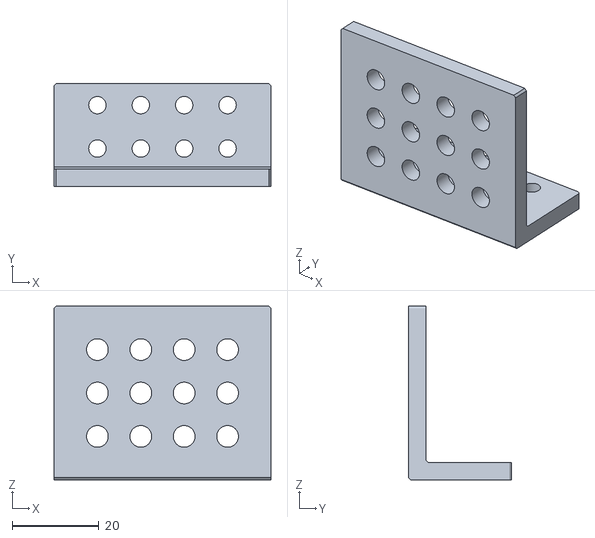
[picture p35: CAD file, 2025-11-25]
parts/translation-stage/LinearStage_L-Bracket.stl
50.0 x 23.8 x 40.0

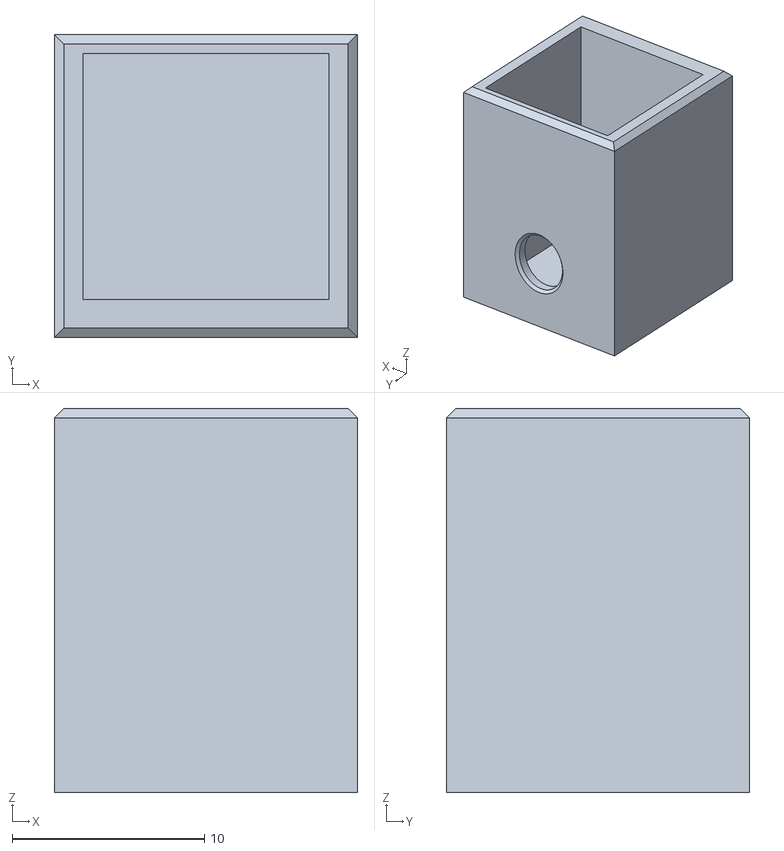
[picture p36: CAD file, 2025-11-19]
parts/basic-assembly/Kuvettecase_Bottom.stl
15.8 x 15.8 x 20.0

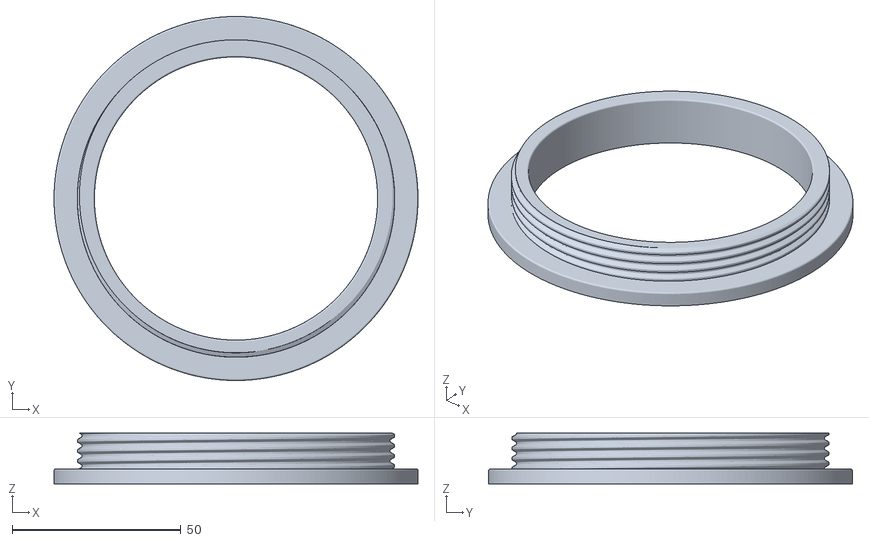
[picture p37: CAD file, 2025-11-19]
parts/glovebox/Glove-Insert_Inner.stl
108.0 x 108.0 x 15.0

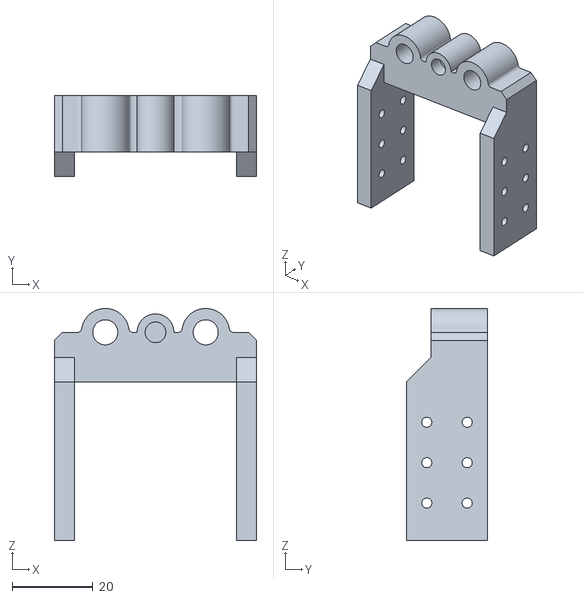
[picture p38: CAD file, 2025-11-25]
parts/translation-stage/LinearStage_Stage.stl
50.0 x 20.0 x 57.4

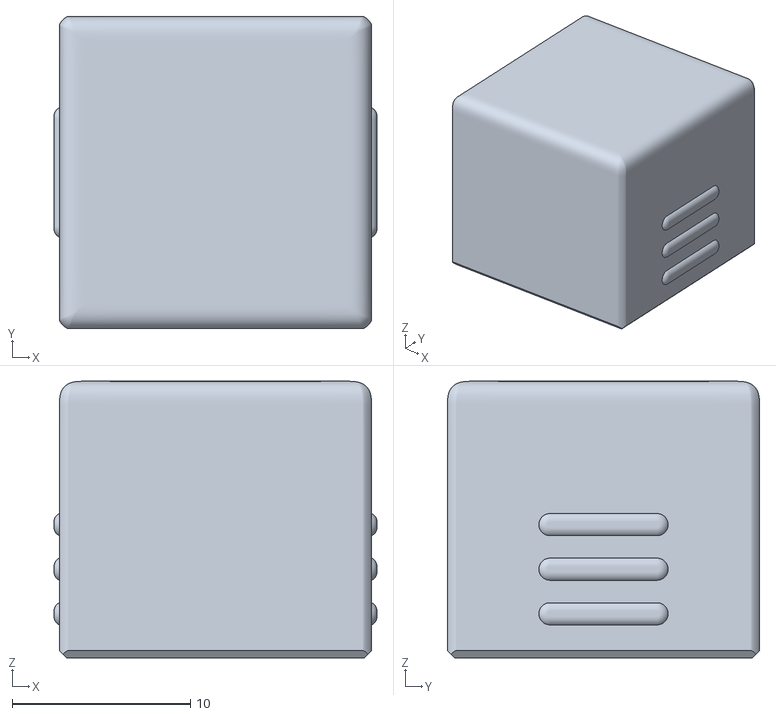
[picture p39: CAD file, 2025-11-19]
parts/basic-assembly/Kuvettecase_Top.stl
18.1 x 17.5 x 15.5

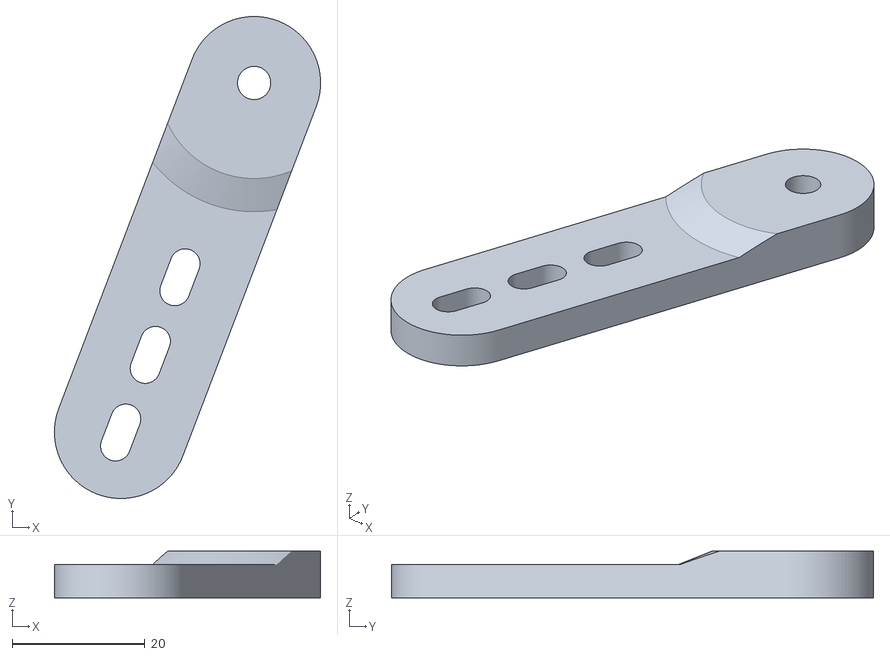
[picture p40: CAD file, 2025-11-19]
parts/glovebox/Fan_Outer-Bracket.stl
40.0 x 72.5 x 7.00

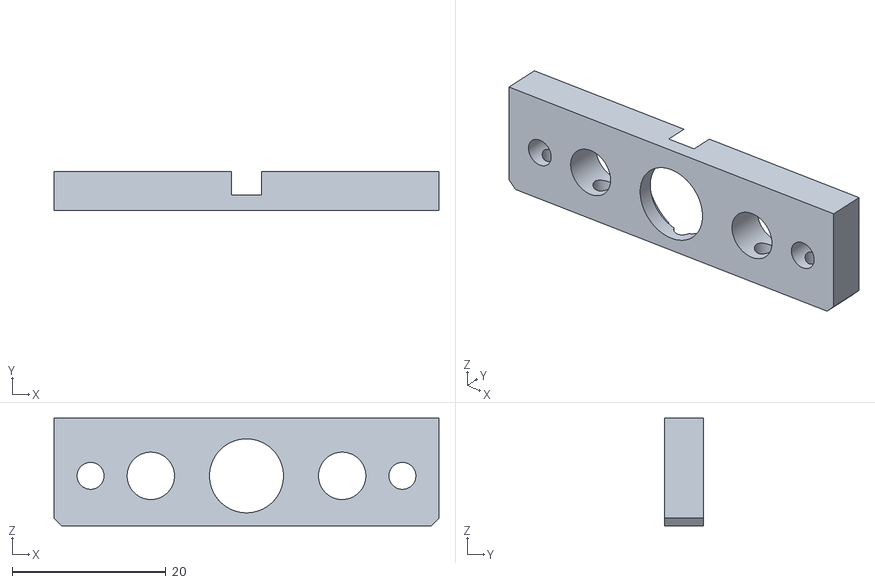
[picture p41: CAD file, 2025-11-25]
parts/translation-stage/LinearStage_Frontplate.stl
50.0 x 5.00 x 14.0

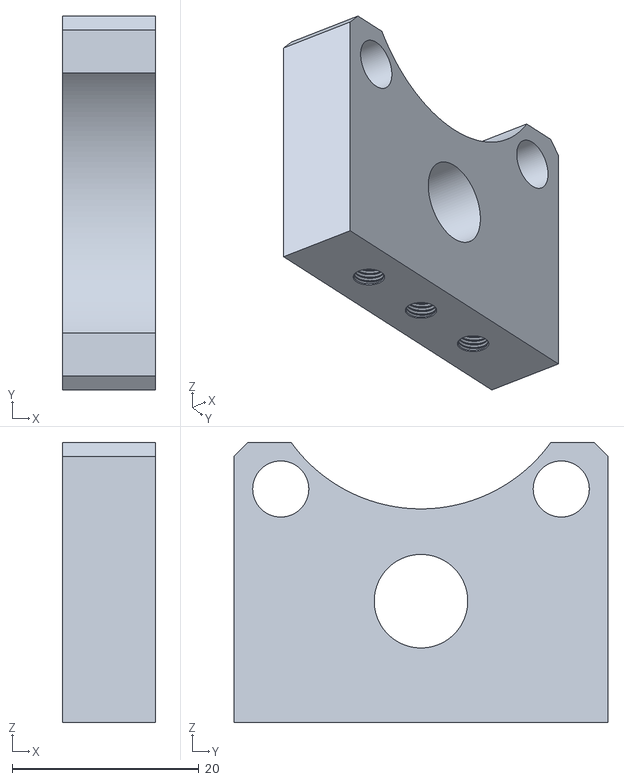
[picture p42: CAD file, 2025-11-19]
parts/basic-assembly/Alternative_Rodholder_Threaded.stl
10.0 x 40.0 x 30.0

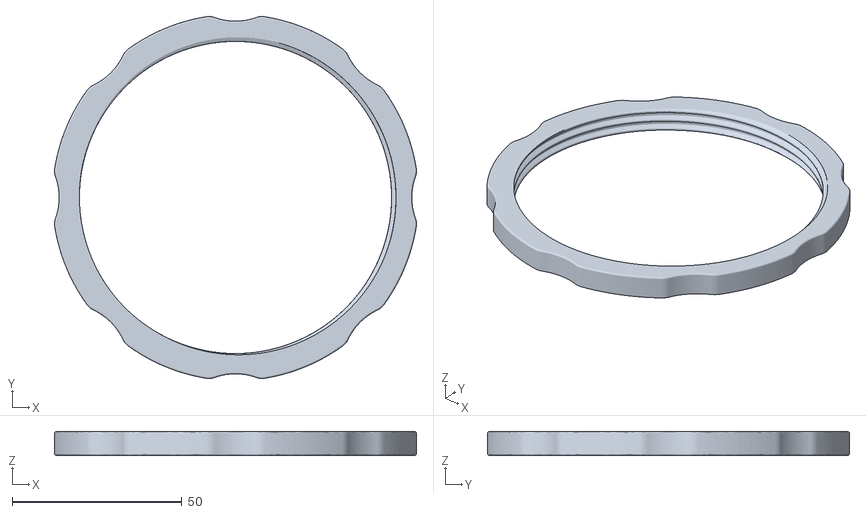
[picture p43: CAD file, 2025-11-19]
parts/glovebox/Glove-Insert_Outer-Ring.stl
106.7 x 106.7 x 7.10

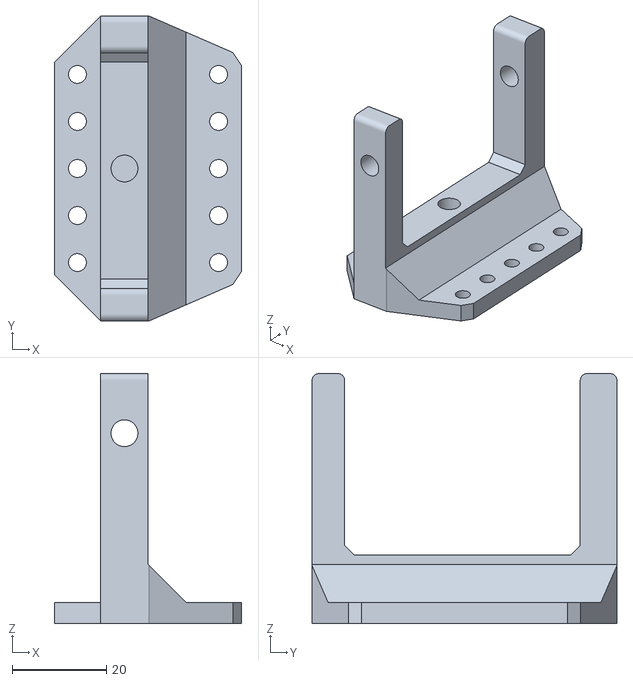
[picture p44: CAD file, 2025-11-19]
parts/basic-assembly/Laser_KM100-Mount.stl
39.8 x 64.8 x 53.2

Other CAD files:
parts/glovebox/Filter_Holder-Clamp.stl
parts/basic-assembly/Dichroic_KM100-Mount.stl
parts/glovebox/Fan_Baseplate.stl
parts/basic-assembly/Sample-Stage.stl
parts/basic-assembly/Baseplate_Small.stl
parts/basic-assembly/Defaultholder.stl
parts/basic-assembly/Objective-Mount_Insert.stl
parts/basic-assembly/SMA905_Insert.stl
parts/glovebox/Cable-Insert_Nut.stl
parts/spectrometer-unit/Spectrometer_Screw-Cover.stl

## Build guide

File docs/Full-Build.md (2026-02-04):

# Full Build

This is currently a placeholder, as I'm working on the next iteration of the build. The [Core-Assembly](Core-Assembly.md) can be easily appended with the [DIY-Linear-Stage](DIY-Linear-Stage.md) and the motorized KM100 mount, which is briefly featured in my Youtube video. If you have any questions or need those unpolished files or code, feel free to reach out though! 



## Pre-Requisites: 

- [Core-Assembly](Core-Assembly.md)
- Motorized KM100 Mount

## Optional 

- [DIY-Linear-Stage](DIY-Linear-Stage.md)
- [Dustproof-Workspace](Dustproof-Workspace.md)
- Spectrometer Unit Case

--------------------------

## Lorem Ipsum



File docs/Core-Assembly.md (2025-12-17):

# Core Optical Assembly

Basic Raman optical assembly overview

Build the basic optical assembly for the DIYraman setup in a *backscattering* configuration. This module provides the minimum optical path you need to record your first Raman spectra.

The design shown here is built around a surplus [B&W Tek spectrometer module](https://www.ebay.com/itm/143989529085), which is commonly available on the used market for around 200€. Other spectrometers with a similar input geometry / SMA905-connector can also be adapted.

For cost reasons, this setup uses a low-cost 532 nm green laser pointer together with a dichroic mirror (cut-on 550 nm) and a longpass filter (cut-on 550 nm). You can find more information in the respective [Parts and Materials](#Parts%20and%20Materials) sections  below or in the [BOM](../bom/BOM.md). Because the laser operates at 532 nm and the filters begin transmitting at 550 nm, the usable Raman signal will be in the Stokes region above roughly 600 cm⁻¹.

> [!NOTE] Full vs. Basic Optical Assembly  
> The [Full-Build](Full-Build.md) incorporates the [DIY-Linear-Stage](DIY-Linear-Stage.md) along with two stepper motors to motorise the kinematic laser mount for convenience.  
> The basic setup on this page is intentionally simpler and sufficient to capture your first Raman signals.

---

## Sub-Assemblies

| Sample assembly overview | Laser assembly overview |
| --- | --- |
| [**Sample Assembly**](#sample%20assembly)<br/><br/>Holds the cuvette and microscope objective on two guide rods. | [**Laser Assembly**](#laser%20assembly)<br/><br/>Mounts the excitation laser in a Thorlabs KM100 kinematic mirror mount. |
| Focusing assembly overview | Dichroic assembly overview |
| [**Focusing Assembly**](#focusing%20assembly)<br/><br/>Filters and focuses the collected signal light towards the fibre / spectrometer input. | [**Dichroic Assembly**](#dichroic%20assembly)<br/><br/>Holds the dichroic mirror that separates laser light from Raman signal. |

---

## Sample Assembly

Exploded view of the sample assembly

The sample assembly positions the cuvette in front of the microscope objective on a pair of guide rods. Before printing and assembling the parts, make sure that your sourced components (cuvette, rods, objective) match the dimensions of the printed holders.

### Parts and Materials

> [!EXAMPLE] Visit the complete Bill of Materials
> Everything you will need, both printed parts and sourced parts, along with their cost and supplier, can be viewed in the dedicated [BOM](../bom/BOM.md)!

#### Sourced parts

| Qty | Name | Model / Spec. | Notes |
| --- | --- | --- | --- |
| 1x  | Quartz Cuvette | Any | Matching the dimensions of `Kuvettecase_Bottom` and `Kuvettecase_Top`. |
| 1x  | Microscope objective | Any, Leitz PL Fluotar 20x/0.45 D EPI, oo/0 | Any, 20x, inf.- corrected, WD > Cuvette-Thickness (alternative to printed part: [CP42/M](https://www.thorlabs.de/thorproduct.cfm?partnumber=CP42/M)) |
| 2x  | Guide Rod ⌀ 6 mm, 100 mm | Any, [ER Assembly Rods for 30 mm Cage Systems](https://www.thorlabs.de/newgrouppage9.cfm?objectgroup_ID=4125) i.e. [ER4](https://www.thorlabs.de/thorproduct.cfm?partnumber=ER4) (4" ~ 100 mm) | Ideally for optical applications (tight tolerances) |
| 2x  | M3 screw + nut | | |

#### Printed parts

| Qty | Part name (.stl) | Print preview |
| --- | --- | --- |
| 1x  | `Defaultholder` | Print orientation of Defaultholder |
| 2x  | `Rodholder` | Print orientation of Rodholder |
| 1x  | `Sample-Stage` | Print orientation of Sample-Stage |
| 1x  | `Kuvettecase_Top` | Print orientation of Kuvettecase_Top |
| 1x  | `Kuvettecase_Bottom` | Print orientation of Kuvettecase_Bottom |
| 1x  | `Objective-Mount_Insert` | Print orientation of Objective-Mount_Insert |

> [!WARNING] Before you print  
> Make sure your sourced parts are compatible with the printed parts:  
> - Are the rods the correct diameter for the rod holders?  
> - Does your cuvette fit into the `Kuvettecase_Bottom` and `Kuvettecase_Top`?  
> - Does your microscope objective fit into the `Objective-Mount_Insert`?

> [!TIP] Quick compatibility checklist  
> - Cuvette → `Kuvettecase_Bottom` / `Kuvettecase_Top` → `Sample-Stage`  
> - Microscope objective → `Objective-Mount_Insert` → `Defaultholder`  
> - Rods → `Rodholder` → `Sample-Stage` → `Objective-Mount_Insert` → `Defaultholder`

Once you have confirmed that your parts match, you can print the components and validate their fit using the steps below.

---

### Step 1 – Check rod fit

**Affected parts**

- `Defaultholder`  
- `Rodholder` (2×)  
- `Sample-Stage`  
- `Objective-Mount_Insert`  

To ensure the printed parts slide smoothly but without play on the rods, test-fit a rod through each opening in the parts listed above.

Checking rod fit in the sample assembly

- The rod should pass through with a noticeable but reasonable amount of force. A snug fit minimises wobble and keeps the optical axis stable.  
- If the rod does not fit at all, lightly sand the edges of the holes and try again.  
- If sanding is not enough, slightly increase the hole compensation (or scale the holes) in your slicer settings and re-print the affected parts.

> [!WARNING] When sanding printed parts  
> Fine plastic dust can be harmful if inhaled. Work in a well-ventilated area, wear a dust mask, and wipe the parts with a damp cloth after sanding to remove any remaining dust.

---

### Step 2 – Install the microscope objective

1. Slide the `Objective-Mount_Insert` into the `Defaultholder` and confirm a smooth, wobble-free fit.  
2. Insert your microscope objective into the `Objective-Mount_Insert`.  
3. Insert two M3 screws and two nuts into the clamp mechanism on the side of the mount, as shown in the illustration.

Installing the microscope objective in the holder

4. Make sure the objective sits straight and level in the mount.  
5. Gently tighten both M3 screws until the objective is held firmly.  
6. Check from the side that the objective remains aligned parallel to the rods (its optical axis should be parallel to the rod direction).

Checking the axial alignment of the microscope objective

> [!WARNING] Do not overtighten  
> Tightening the screws too much can deform the printed part or the objective barrel. Tighten only until the objective no longer moves if you tap it lightly.

---

### Step 3 – Check the cuvette holder

1. Place your cuvette into the `Kuvettecase_Bottom`. Confirm that the contents of the cuvette are visible through the circular opening in the bottom part.

Checking cuvette fit in the bottom holder

2. Slide the `Kuvettecase_Top` over the `Kuvettecase_Bottom` with the cuvette inside. The top should sit tightly and close with some friction.  
3. If the `Kuvettecase_Top` is too tight, lightly sand the inside surfaces. Afterwards, wipe off dust with a damp cloth.  
4. If it still does not fit, slightly scale the `Kuvettecase_Top` in your slicer (for example, to 101 % in X/Y/Z) and re-print.  
5. The cover is optional but recommended to reduce spills and minimise stray light entering from above.

---

### Step 4 – Assemble the sample sub-assembly

1. Place both `Rodholder` parts upright on your workspace and push both rods through the first `Rodholder`.  
2. Slide the `Defaultholder` (with mounted objective and insert) and then the `Sample-Stage` onto both rods, as shown in the graphic.

Assembling the sample sub-assembly

3. Push the second `Rodholder` onto the rods to lock the parts in place.  
4. Place the `Kuvettecase_Bottom` with the cuvette on the `Sample-Stage` so that the opening faces the microscope objective. It should sit loosely but stably on the stage.

Sample sub-assembly – assembled drawing

---

## Laser Assembly

Exploded view of the laser assembly

The laser assembly holds a cylindrical laser module in a Thorlabs KM100 kinematic mount using a printed adapter and heat-set threaded inserts.

### Parts and Materials

> [!EXAMPLE] Visit the complete Bill of Materials
> Everything you will need, both printed parts and sourced parts, along with their cost and supplier, can be viewed in the dedicated [BOM](../bom/BOM.md)!

#### Sourced parts

| Qty  | Name | Model / Spec. | Notes |
| ---- | --- | --- | --- |
| 1x | Laser 532nm | Any, 532 nm DPSS, 30mW - 70mW, (⌀ 18 mm) | Cylindrical laser module, 18 mm body. |
| 1x | Kinematic Mount | Thorlabs KM100 | Kinematic mirror mount. |
| 2-3x | M4 heat-set insert | | |
| 1x | M3 heat-set insert | | |

#### Printed parts

| Qty | Part name (.stl) | Print preview |
| --- | --- | --- |
| 1x  | `Laser_KM100-Insert` | Print orientation of Laser_KM100-Insert |
| 1x  | `Laser_KM100-Mount`  | Print orientation of Laser_KM100-Mount |

> [!WARNING] Before you print  
> Check that the laser body diameter matches the `Laser_KM100-Insert`.

---

### Step 1 – Prepare the printed KM100 mount (heat-set inserts)

1. Insert an M4 brass heat-set insert (slim side first) into the centre opening on the bottom of the `Laser_KM100-Mount`.  
2. Using a hot soldering iron with a flat tip, gently press on the insert until the surrounding plastic softens and the insert sinks into the part.  
3. Stop when the insert is slightly below the plastic surface. The KM100 will sit on this face, so it should remain flat.

Melting heat-set inserts into the KM100 base mount

4. Repeat the process for the side holes in the mount where additional M4 inserts are required (see illustration).  
5. Allow the part to cool completely before mounting any hardware.

> [!TIP] Tools for heat-set inserts  
> A temperature-controlled soldering iron with a flat tip works well. Dedicated heat-set insert tips are inexpensive and make this step easier.

---

### Step 2 – Prepare the laser insert (`Laser_KM100-Insert`)

1. Heat-set the M3 insert into the small side hole of the `Laser_KM100-Insert`.  
2. Make sure the insert does not protrude into the inner bore where the laser will sit. A slight protrusion on the outside is fine.

Melting the M3 insert into the laser adapter

---

### Step 3 – Mount the KM100 in the printed base

1. Place the KM100 on top of the `Laser_KM100-Mount` so that the central hole in the KM100 aligns with the centre M4 insert.  
   - The rotation of the KM100 is not critical at this point; the printed mount supports multiple orientations.  
2. Use one of the supplied M4 screws to fasten the KM100 to the mount. Tighten only until the mount no longer moves freely.  
3. Use a second screw in one of the side slots if desired to further stabilise the mount.

Mounting the KM100 on the printed base

---

### Step 4 – Insert the printed laser adapter

1. Check that the small nylon set screw on the KM100 (perpendicular to the front opening) is loosened so that it does not block the aperture.  
2. From the front of the KM100, push the `Laser_KM100-Insert` into the circular opening. It should seat firmly but without excessive force.  
3. Apply light pressure with both thumbs until the front face of the printed insert is flush with the inner reference ring of the KM100.  
4. Lightly tighten the nylon set screw on the KM100 to hold the printed insert in place.

---

### Step 5 – Insert the laser module

1. From the back of the mount, slide the laser module into the `Laser_KM100-Insert` that is now fixed inside the KM100.

Installing the laser module into the adapter

   - The exact insertion depth is not critical. Ideally, the laser front face is close to flush with the front of the `Laser_KM100-Insert`.  
2. Insert an M3 screw into the M3 heat-set insert in the side of the `Laser_KM100-Insert` and gently tighten it until the laser is held securely.

Laser assembly – assembled drawing

> [!WARNING] Avoid crushing the laser body  
> Do not overtighten the M3 clamping screw. Tighten only until the laser can no longer rotate or slide when you try to move it by hand.

---

## Focusing Assembly

Exploded view of the focusing assembly

The focusing assembly combines the longpass filter, focusing lens and (optionally) an SMA905 fibre adapter on a pair of rods. This module filters and focuses the Raman signal into the spectrometer input.

### Parts and Materials

> [!EXAMPLE] Visit the complete Bill of Materials
> Everything you will need, both printed parts and sourced parts, along with their cost and supplier, can be viewed in the dedicated [BOM](../bom/BOM.md)!

#### Sourced parts

| Qty | Name | Model / Spec. | Notes |
| --- | --- | --- | --- |
| 1x  | Longpass filter (550 nm) | Thorlabs FELH0550 | |
| 1x  | Focusing lens | [Thorlabs AC127-019-A](https://www.thorlabs.de/thorproduct.cfm?partnumber=AC127-019-A) - f = 19 mm, Ø1/2" Achromatic Doublet | (mounted in [CP32/M](https://www.thorlabs.com/thorproduct.cfm?partnumber=CP32/M)) |
| 2x  | Guide Rod ⌀ 6 mm, 100 mm | Any, [ER Assembly Rods for 30 mm Cage Systems](https://www.thorlabs.de/newgrouppage9.cfm?objectgroup_ID=4125) i.e. [ER4](https://www.thorlabs.de/thorproduct.cfm?partnumber=ER4) (4" ~ 100 mm) | Ideally for optical applications (tight tolerances) |
| 6x  | M3 heat-set insert | | |
| 6x  | M3 screws | | |

#### Printed parts

| Qty | Part name (.stl) | Print preview |
| --- | --- | --- |
| 3x  | `Defaultholder`  | Print orientation of Defaultholder |
| 2x  | `Rodholder` | Print orientation of Rodholder |
| 1x  | `SMA905_Insert`  | Print orientation of SMA905_Insert |

> [!WARNING] Before you print  
> Confirm that the longpass filter and focusing lens diameters match the openings in the printed `Defaultholder` parts.

---

### Step 1 – Check rod fit (again)

The rod fit procedure is identical to **[Step 1 – Check rod fit](#step1--check-rod-fit)** in the sample assembly:

- Test-fit the rods through all `Rodholder` parts and through the bores in each `Defaultholder` that will sit on the rods.  
- Adjust with light sanding or slicer hole compensation if necessary.

---

### Step 2 – Prepare the holders (heat-set inserts)

1. Identify the clamping points in the `Defaultholder` parts where screws will press on the longpass filter, focusing lens and SMA905 insert.  
2. Heat-set M3 inserts in all corresponding holes so that the inserts sit slightly below the plastic surface.  
3. Let the parts cool fully before inserting any optics.

> [!WARNING] Handle optics only after plastic has cooled  
> Hot plastic can warp or damage optical coatings. Always complete all heating/soldering steps before inserting filters or lenses.

---

### Step 3 – Assemble the focusing module

1. Insert both rods into the first `Rodholder`.  
2. Slide the three `Defaultholder` blocks onto the rods in the following order (from the sample side towards the spectrometer side):  
   - `Defaultholder` with the `SMA905_Insert` and connected SMA905 fibre (if used).  
   - `Defaultholder` holding the focusing lens.  
   - `Defaultholder` holding the longpass filter.  
3. Push the rods through the second `Rodholder` to lock the sequence of holders in place.

Focusing assembly – assembled drawing

> [!TIP] Orientation of optics  
> Make sure you keep track of which side of the longpass filter and focusing lens should face the incoming light, according to their datasheets. If in doubt, mark the correct side with a small sticker on the edge before mounting.

---

## Dichroic Assembly

Exploded view of the dichroic assembly

The dichroic assembly mounts a Thorlabs dichroic mirror in a KM100 kinematic mount, held by a printed base that will later sit on the main baseplate. The dichroic separates the excitation laser from the Raman signal.

### Parts and Materials

> [!EXAMPLE] Visit the complete Bill of Materials
> Everything you will need, both printed parts and sourced parts, along with their cost and supplier, can be viewed in the dedicated [BOM](../bom/BOM.md)!

#### Sourced parts

| Qty | Name | Model / Spec. | Notes |
| --- | --- | --- | --- |
| 1x  | Kinematic Mount | Thorlabs KM100 | Kinematic mirror mount. |
| 1x  | Dichroic mirror (550 nm) | Thorlabs DMLP550 | |
| 1x  | M4 heat-set insert | | |

#### Printed parts

| Qty | Part name (.stl) | Print preview |
| --- | --- | --- |
| 1x  | `Dichroic_KM100-Mount` | Print orientation of Dichroic_KM100-Mount |

---

### Step 1 – Prepare the printed KM100 mount

1. Insert the M4 heat-set insert into the central hole of the `Dichroic_KM100-Mount`.  
2. Using a hot soldering iron, press the insert straight into the opening until it sits slightly below the plastic surface.  
3. Position the KM100 on the `Dichroic_KM100-Mount` so that the bottom screw hole aligns with the M4 insert.  
4. Use one of the provided M4 screws to fasten the KM100 to the mount until it no longer moves freely, but can still be rotated with gentle force.

> [!NOTE] Rotation during alignment  
> Later, on the baseplate, the KM100 will be rotated to 45° with respect to the incoming laser beam. You will slightly loosen this screw again to set that angle.

---

### Step 2 – Install the dichroic mirror

> [!WARNING] Handle optics carefully  
> Work in a clean area and wear powder-free nitrile gloves. Avoid touching the coated surfaces and never wipe them with dry cloths.

Spectral performance of the Thorlabs DMLP550 dichroic mirror at 45° AOI  
_Source: Thorlabs – “Longpass Dichroic Mirrors/Beamsplitters”_

1. Review the Thorlabs handling guide for high-performance optics:  
   [Thorlabs – Optics Handling and Care](https://www.thorlabs.com/newgrouppage9.cfm?objectgroup_id=9025).  
2. The dichroic mirror is directional: one side carries the dichroic coating (reflecting the laser, transmitting the Raman signal), the other side carries an anti-reflection (AR) coating.  

Orientation of the dichroic coating on the DMLP550  
_Source: Thorlabs – “Longpass Dichroic Mirrors/Beamsplitters”_

3. On the Thorlabs DMLP550, the **dichroic side is indicated by a small engraved arrow pointing towards the coated surface**. This arrow is etched on the outer edge and can be hard to see in dim light.  
4. With clean powder-free nitrile gloves, carefully hold the dichroic by its outer edge and locate the engraved arrow.  
5. Insert the dichroic mirror into the KM100 so that:  
   - The dichroic (arrow-marked) side faces the incoming laser beam (front side).  
   - The AR-coated side faces towards the KM100 adjustment knobs (back side).  
6. Gently tighten the nylon set screw on the KM100 until the dichroic sits evenly and flush in the mount.

Dichroic assembly – assembled drawing

---

## Baseplate Mounting

Basic assembly mounted on the baseplate

In this final step you mount all sub-assemblies onto the baseplate to form the complete basic Raman optical assembly.

### Parts and Materials

> [!EXAMPLE] Visit the complete Bill of Materials
> Everything you will need, both printed parts and sourced parts, along with their cost and supplier, can be viewed in the dedicated [BOM](../bom/BOM.md)!

#### Sourced parts

| Qty | Name | Notes |
| --- | --- | --- |
| 1x  | [Sample Assembly](#Sample%20Assembly) | |
| 1x  | [Laser Assembly](#Laser%20Assembly) | |
| 1x  | [Focusing Assembly](#Focusing%20Assembly) | |
| 1x  | [Dichroic Assembly](#Dichroic%20Assembly) | |
| 14x | M4 screw, 16 mm | For fastening sub-assemblies to the baseplate. |
| 6x  | M4 nut | For additional clamping where required. |

#### Printed parts

| Qty | Part name (.stl)  | Print preview | Notes |
| --- | --- | --- | --- |
| 1x  | `Baseplate_Small` | Print orientation of Baseplate_Small | 250 × 140 × 7 mm |

---

### Step 1 – Mount the sub-assemblies onto the baseplate

Assembly steps for mounting all sub-assemblies

1. Mount the [Sample Assembly](#sample-assembly) using four M4 screws from the bottom of the baseplate.  
2. Mount the [Laser Assembly](#laser-assembly) using four M4 screws from the bottom and four M4 nuts from above to tighten.  
3. Mount the [Focusing Assembly](#focusing-assembly) using four M4 screws from the bottom.  
4. Mount the [Dichroic Assembly](#dichroic-assembly) using two (or four) M4 screws from the bottom and the corresponding M4 nuts from above.

> [!NOTE] Fine-tune the dichroic assembly  
> The dichroic assembly as a whole is designed to move in X/Y direction to allow for positional adjustments. You may want to re-position the assembly within the bounds of its mount later on, so do not overtighten screws and nuts at this stage.

Sub-assemblies mounted on the baseplate – line art

---

## Continue reading

- [Spectrometer-Setup](Spectrometer-Setup.md)
- [SpectrumStudio-Cheatsheet](SpectrumStudio-Cheatsheet.md)
- [Align-with-Fluorescence](Align-with-Fluorescence.md)
- [Build the Linear Translation Stage](DIY-Linear-Stage.md)  
- [Build the Overpressure Glovebox](Dustproof-Workspace.md)  
- [Build the Full Assembly](Full-Build.md)

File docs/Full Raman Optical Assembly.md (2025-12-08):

PLACEHOLDER PAGE



## Pre-Requisites: 

- [Linear Translation Stage](Linear%20Translation%20Stage.md)
- [Overpressure Glove Box](Overpressure%20Glove%20Box.md)
- Spectrometer Unit Case

--------------------------

## Lorem Ipsum



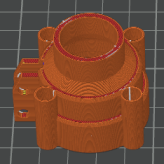
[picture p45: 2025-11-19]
assets/images_print-orientation/Print-Orientation_Objective-Mount_Insert_164px_PNG.png

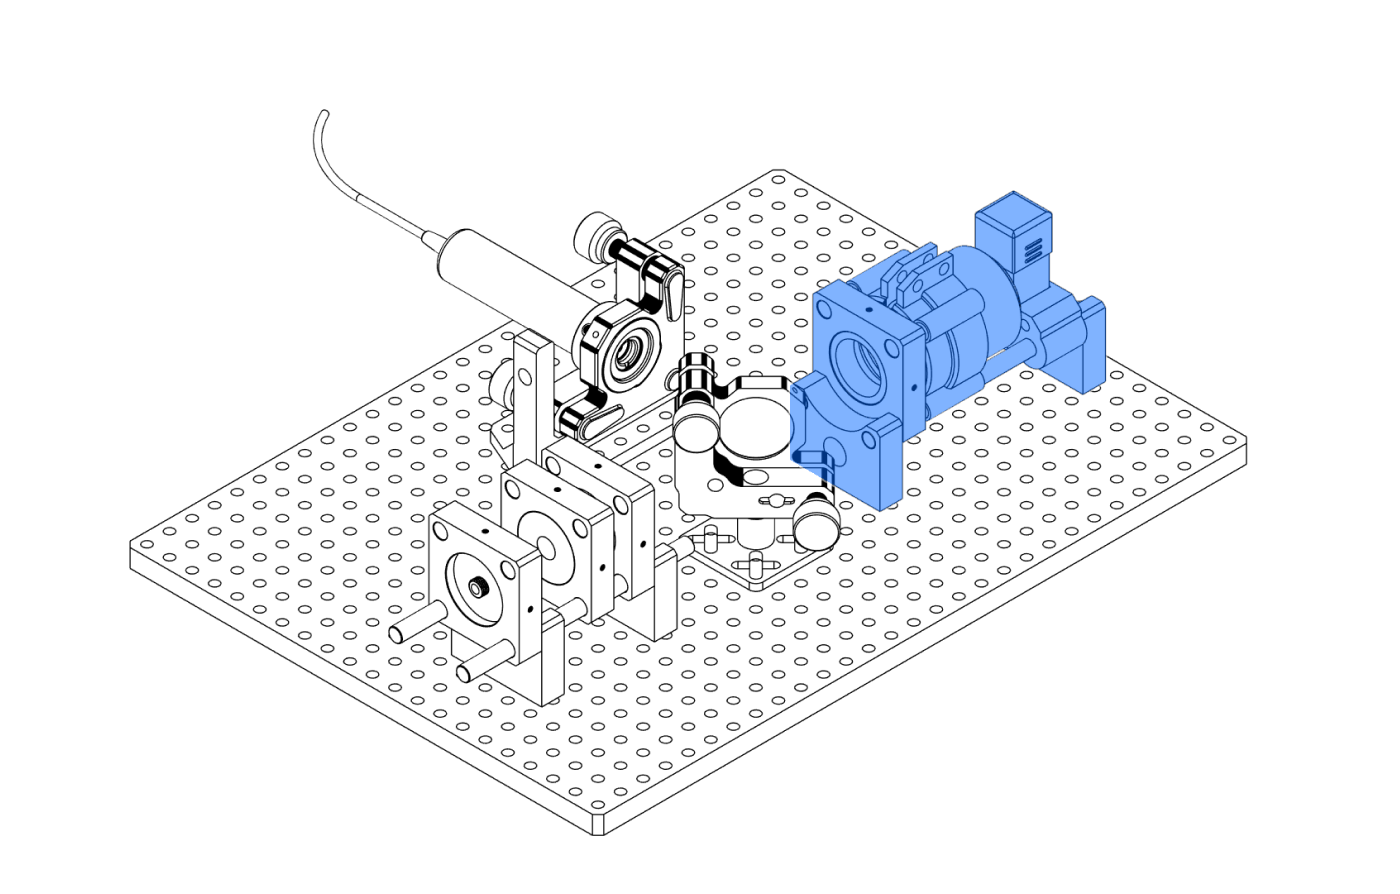
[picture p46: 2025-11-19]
assets/images_picked/Raman-Optical-Assembly/Sample-Basic-Assembly-1400px_Screenshot_PNG-1.png

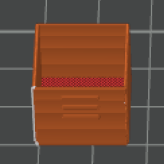
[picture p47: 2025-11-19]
assets/images_print-orientation/Print-Orientation_Kuvettecase_Top_164px_PNG.png

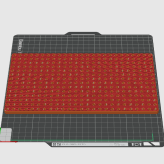
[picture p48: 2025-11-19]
assets/images_print-orientation/Print-Orientation_Baseplate_Small_164px_PNG.png

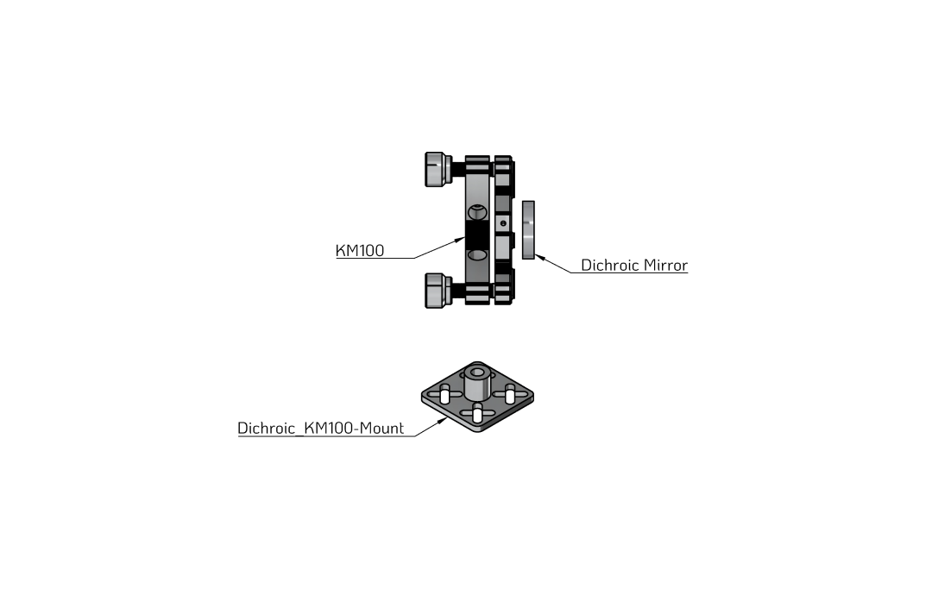
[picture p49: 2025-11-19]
assets/images_picked/Raman-Optical-Assembly/Dichroic_Exploded-Drawing_Annotated-Shaded_PNG.png

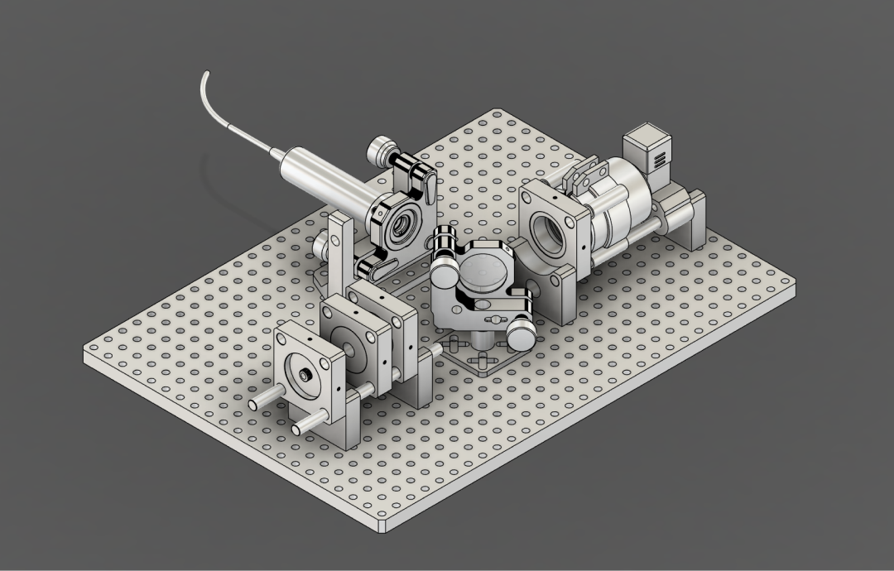
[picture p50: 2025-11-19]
assets/images_picked/Raman-Optical-Assembly/ShadedGray-Full-Basic-Assembly-1080px_Screenshot_PNG.png

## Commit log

2025-11-19 Initial commit 0.1
    Clone entire obsidian vault, including all pictures and WiP files.
    [Baseplate_Small.stl, Cable-Insert_Nut.stl, Defaultholder.stl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]
2025-11-25 Update and Cleanup
    Updated BOM.md, cleaned up files, improved coherence + more assets for Linear Translation Stage
    [LinearStage_Base.stl, LinearStage_Frontplate.stl, LinearStage_L-Bracket.stl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]
2025-11-25 Mirrored BOM + Fixed image on README.md
2025-11-26 Quick adjustment
    + Added - Laser optical path overview graphic
2025-11-30 Minor update v0.2
    - Added draft for Rhodamine B
    - Cleaned up BOM further
    - Various small adjustments
    [Alternative_Rodholder_Threaded.stl, Rodholder.stl]
2025-12-07 Big revision - streamlined all parts
    - New updated BOM
    - Consistent formatting for sourced and printed parts in every doc
2025-12-07 Added print previews
    - Overpressure Glove Box
    - Spectrometer Unit
    - Added .stl-part cover for spectrometer input thread
    [Spectrometer_Screw-Cover.stl]
2025-12-08 BOM namechange #1
2025-12-08 BOM filename changed #2
2025-12-08 Adapted BOM filename
2026-02-03 Update BOM - Prepend paths linking to Core-Assembly

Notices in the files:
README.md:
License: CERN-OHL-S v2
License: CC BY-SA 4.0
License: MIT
